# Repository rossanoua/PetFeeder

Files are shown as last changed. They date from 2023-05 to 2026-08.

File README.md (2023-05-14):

# PetFeeder

This is Arduino library for pet feeder.

### Hardware
- Arduino Uno.
- Stepper motor NEMA17 17HS4401, it will be used to push food through plastic tube with auger.
- Vibration motor, so that the feed does not get stuck in the pipe.
- 7 segment 4 digit LED display with TM1637 driver for display some info right on the feeder.
- A button, by clicking on it, feeder will push one portion of food for my pet.
- Tension sensor and HX711 to get to know what weight we need to push more.
- HC-06 bluetooth module, to have possibility to have some comfortable way to customise my feeder. 

### What inspired me
- Actually, the Arduino itself, to be honest.
- Another projects. Like [Gyver Feeder](https://github.com/AlexGyver/GyverFeed2)

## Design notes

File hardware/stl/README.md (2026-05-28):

# Printable meshes (STL)

Generated from `../cad/openscad/feeder_test_module.scad` — **the .scad is
the source of truth**, these are build artifacts. 3MF copies are in
`../3mf/` (OrcaSlicer reads both; 3MF preserves units, prefer it).

> OpenSCAD cannot export STEP (it is mesh-based, STEP is CAD/BREP).
> OrcaSlicer *does* import STEP, but for these parts STL/3MF is enough.

Regenerate after editing the model:

```sh
cd hardware/cad/openscad
for p in auger axle barrel hopper; do
  openscad -o ../../stl/$p.stl  -D "part=\"$p\"" feeder_test_module.scad
  openscad -o ../../3mf/$p.3mf -D "part=\"$p\"" feeder_test_module.scad
done
```

## Suggested print orientation (Stage 1 test, tune later)

- **auger** — vertical, shaft axis along Z, supports off / tree. The
  helical flight self-supports reasonably; a brim helps adhesion on the
  small base. This is the part most sensitive to print quality.
- **axle** — better to use a Ø5 mm steel rod. If printed: vertical,
  thin — expect flex and wear, test-only.
- **barrel** — vertical (bore along Z). Bore prints without supports;
  the inlet/socket may need light supports on its overhangs.
- **hopper** — print upside down (wide opening on the bed) so the cone
  and spout self-support; no supports inside the funnel.

All exported manifold (OpenSCAD `Simple: yes`). Fit clearances
(`fit_clear`, `join_clear`, `barrel_clear`) are guesses — adjust in the
.scad and reprint test coupons until the slip fits feel right on your
printer. Record results in `docs/mechanical-tests.md`.

## Paddle wheel parts (`pw_*`)

Source: `../cad/openscad/paddle_wheel_module.scad`. Same axle interface
(Ø5 mm with D-flat) as the auger, so one printed axle works for both
benchmarks.

```sh
cd hardware/cad/openscad
for p in wheel axle housing end_cap hopper; do
  openscad -o ../../stl/pw_$p.stl -D "part=\"$p\"" paddle_wheel_module.scad
  openscad -o ../../3mf/pw_$p.3mf -D "part=\"$p\"" paddle_wheel_module.scad
done
```

Suggested orientation:

- **pw_wheel** — flat on bed, hub axis vertical. Paddles on the bottom
  half (closer to the bed) self-support; no supports needed.
- **pw_axle** — use a Ø5 mm steel rod if possible.
- **pw_housing** — bed-down on the closed floor (open top facing up).
  No overhangs to support — the floor is flat and the outlet is a clean
  through-hole in the floor.
- **pw_end_cap** — flat on the bed, register lip pointing UP, boss
  pointing up. Boss has a flat overhanging roof — needs light supports
  if you print it cap-down. Or print boss-down (boss touching the bed)
  to avoid supports inside the socket. Pick whichever your slicer
  handles better.
- **pw_hopper** — upside down (wide opening on the bed).

Assembly order:
1. Slide the axle up through the housing's bottom bore (motor stub
   exits below the floor).
2. Drop the wheel onto the axle inside the housing (D-flat keys it).
3. Drop the cap onto the rim — the register lip seats in the recess,
   and the upper axle stub passes through the cap bore.
4. Slide the hopper spout into the boss-socket on top of the cap.

**Mounting note for Stage 1 tests:** the housing rests on its flat
floor BUT the outlet is in that floor. Prop the housing up on small
blocks under the rim (or place it over the bowl on a piece of cardboard
with a hole cut) so kibble can fall through the outlet into the bowl.
The motor coupler attached to the bottom axle stub also works as a
built-in standoff if the motor is mounted below the housing.

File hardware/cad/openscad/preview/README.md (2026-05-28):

# Preview renders

Visual reference only — **not authoritative**. The model is
`../feeder_test_module.scad`; regenerate after any change:

```sh
cd hardware/cad/openscad
xvfb-run -a openscad -o preview/auger.png    --imgsize=1000,700 --autocenter --viewall -D 'part="auger"'    feeder_test_module.scad
xvfb-run -a openscad -o preview/axle.png     --imgsize=1000,500 --autocenter --viewall -D 'part="axle"'     feeder_test_module.scad
xvfb-run -a openscad -o preview/barrel.png   --imgsize=1000,700 --camera=-260,30,46,0,0,46 -D 'part="barrel"'   feeder_test_module.scad
xvfb-run -a openscad -o preview/hopper.png   --imgsize=1000,700 --autocenter --viewall -D 'part="hopper"'   feeder_test_module.scad
xvfb-run -a openscad -o preview/assembly.png --imgsize=1000,750 --camera=-200,-200,150,0,0,35 -D 'part="assembly"' feeder_test_module.scad
```

(`xvfb-run` only needed on headless machines.)

- `auger.png`    — the screw, with the through D-bore for the axle
- `axle.png`     — drive axle: round stubs + D-flat over the middle
- `barrel.png`   — tube, viewed from the inlet side; rectangular socket
  collar with a conical funnel down into the bore (green = bore opened)
- `hopper.png`   — feed cone: round top → rectangular plug-in spout
- `assembly.png` — axle through auger, inside barrel, hopper spout
  seated in the collar socket

Verified with OpenSCAD 2021.01: all parts render `Simple: yes` (manifold,
printable); axle passes through the auger; hopper spout seats in the
collar; funnel leads from the socket into the bore.

Torque path: motor → axle round stub → D-flat → auger → food.
Use a real 5 mm steel rod as the axle if possible (printed axles flex).

---

## Paddle wheel module (`pw_*` files)

Alternative — and now primary — Stage 1 mechanism. Source:
`../paddle_wheel_module.scad`. Regenerate:

```sh
for p in wheel axle housing end_cap hopper; do
  xvfb-run -a openscad -o preview/pw_$p.png --imgsize=1000,750 --autocenter --viewall -D "part=\"$p\"" paddle_wheel_module.scad
done
xvfb-run -a openscad -o preview/pw_assembly.png --imgsize=1100,800 --autocenter --viewall -D 'part="assembly"' paddle_wheel_module.scad
```

- `pw_wheel.png`    — full-height hub + half-height paddles + D-bore
- `pw_axle.png`     — drive axle (round stubs + middle D-flat)
- `pw_housing.png`  — cup-shaped, closed floor with the rectangular
  OUTLET hole, OPEN top, rim recess for the cap
- `pw_housing_top.png` — top-down view; the outlet rectangle in the
  floor is clearly visible at 180° (left side of the disc) and the
  central axle bore at the centre
- `pw_end_cap.png`  — removable lid with the central axle bore + the
  radial-offset inlet hole, and the rectangular boss-socket on top
- `pw_hopper.png`   — feed cone; rectangular spout plugs into the cap
  boss-socket
- `pw_assembly.png` — wheel inside the housing, cap closing the top,
  hopper sitting above the cap with its spout in the boss; axle
  through everything (stubs visible top and bottom)
- `pw_assembly_top.png` — top-down view; inlet (cap boss) at +X / 0°,
  outlet (in the floor below) at 180°; non-coaxial offset = 180°

Real-world mounting: rotate the whole assembly 90° so the axle is
horizontal — then the hopper sits on top (gravity-fed), the chute drops
kibble down to the bowl below.

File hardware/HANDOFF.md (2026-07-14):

# AiPetFeeder — handoff (form 1a)

Стан на 2026-07-13, гілка `feature/feeder-compact-vibro`, останній коміт `72083c6`
(самофіксні стики: байонет + snap-детенти).
Документ для передачі іншому агенту: що це, з чого складається, які **числа не можна
чіпати не порахувавши**, і на які граблі я вже наступив.

---

## 1. Що це

Автогодівниця для кота. Форма **1a**: одна суцільна вежа **Ø160**, що стоїть **плазом
на власному дні** (ніг немає). Корм падає в **неглибокий лоток**, який висувається
вперед і стоїть на тензодатчику. Електроніка живе в кільцевому відсіку між мотором і
стінкою.

Друк: **AONE2 / Klipper**, поле **180 × 180 × 180** — усі деталі туди вписані.

| Вежа в зборі | Вибухова схема |
|---|---|
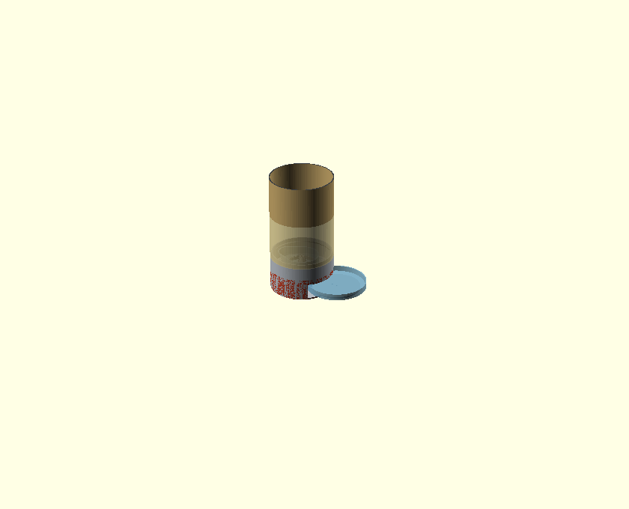
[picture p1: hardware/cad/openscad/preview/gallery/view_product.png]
Вежа в зборі
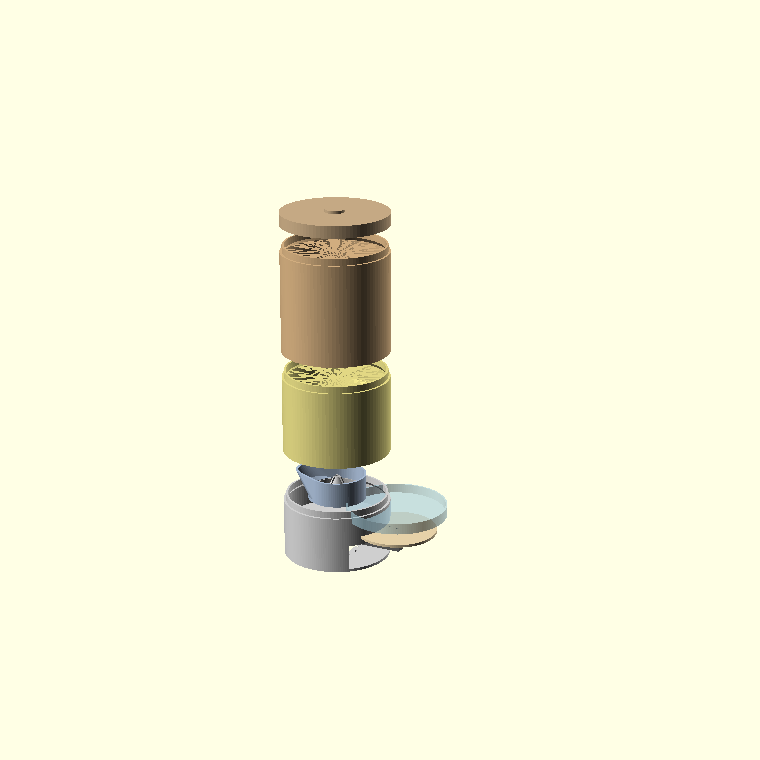
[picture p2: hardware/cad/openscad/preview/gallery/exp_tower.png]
Вибухова схема вежі
|  |  |

| Вибух: база | Вибух: лійка |
|---|---|
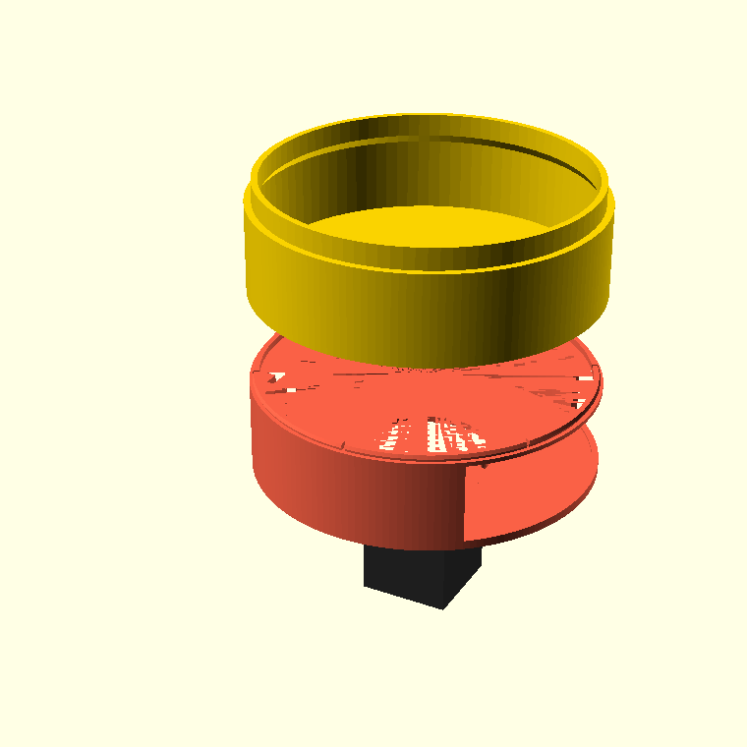
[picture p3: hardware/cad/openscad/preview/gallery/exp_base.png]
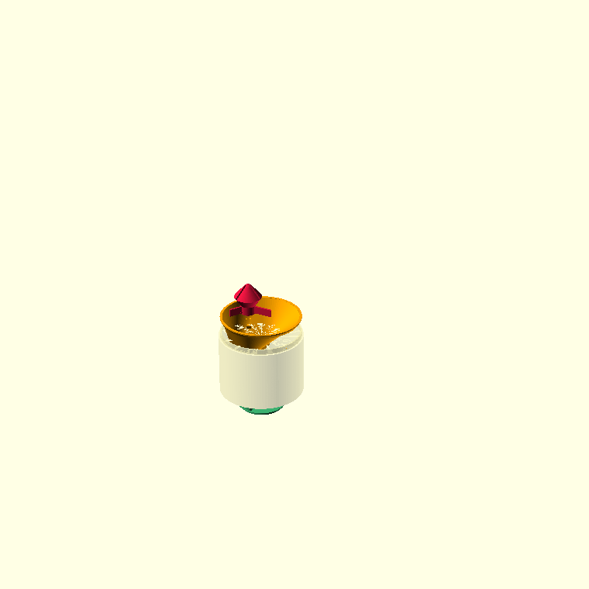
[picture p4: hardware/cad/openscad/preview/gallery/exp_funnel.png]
|  |  |

### Файли

| Файл | Що |
|---|---|
| `cad/openscad/bulk_hopper_module.scad` | **Головний.** Корпус, лійка, банка, лоток, вага, електроніка |
| `cad/openscad/paddle_wheel_module.scad` | Механізм: `wheel`, `housing`, `axle` |
| `cad/openscad/gallery_views.scad` | Розрізи/галерея (не друкується) |
| `cad/openscad/archive/chassis_module.scad` | **DEPRECATED**, не використовувати |
| `cad/openscad/preview/gallery/` | рендери кожної деталі + розрізи |
| `cad/openscad/preview/assembly/` | **як збирається**: step 0–9, розібрані види, розрізи тракту, turntable |

### Осі та z-площини

```
+X = ПЕРЕД (лоток, виток корму)      -X = ЗАД (сервісна панель, електроніка)
+Z = вгору,  z0 = земля (низ дна)

z0 ─── низ / земля
z3 ──── верх дна (sole_t=3); тут лежить load cell
z4 ──── низ ніші (niche_z0)
z40 ─── верх ніші (niche_h) — стеля скалопа
z43 ─── база деки / низ ДИСКА (base_deck_z) = грань мотора; ВИТОК виходить сюди
z48 ─── верх диска (base_motor_h) = підлога housing
z85 ─── верх бази (base_h) = верх housing; сюди сідає лійка
```

---

## 2. Деталі

### Друковані — 16

| # | part= | Габарит | Друк | Роль |
|---|---|---|---|---|
| 1 | `base_motor` | Ø160 × 46 | стоячи, z0 на стіл | Обичайка: дно, скалоп, пʼєдестал cell, рейки електроніки, сервісне вікно, snap-спігот |
| 2 | `base_hopper` | Ø160 × 52 | диском на стіл | Диск (z43–48) з витоком + комірцем; мотор під ним, housing над ним |
| 3 | `housing` (pw) | Ø88 × 37 | native 0° | Камера дозатора |
| 4 | `wheel` (pw) | Ø80 × 29 | плазом | Колесо, 3 лопаті, **Ø5 D-отвір → прямо на вал** |
| 5 | `axle` (pw) | Ø5 × 70 | стоячи | Опційна верхня вісь |
| 6 | `cap` | 110 × 88 × 14 | плазом | Кришка housing (`cap_plate`) |
| 7 | `shell` | Ø160 × 125 | стоячи | Оболонка лійки |
| 8 | `cone` | Ø153 × 83 | горлом донизу | Mass-flow конус |
| 9 | `spider_body` | Ø52 × 58 | куполом угору | Анти-джам, тіло |
| 10 | `spider_legs` | 3 × (95×60×14) | плазом | Анти-джам, 3 леза |
| 11 | `ring` | Ø160 × 160 | стоячи | Банка, ~2.79 л, стековна |
| 12 | `lid` | Ø160 × 22 | плазом | Верхня кришка |
| 13 | `tray` | Ø150 × 16 | плазом | Лоток-миска, ~280 мл |
| 14 | `cell_platform` | Ø120 × 6 | плазом | Площадка на cell |
| 15 | `el_tray` | 80 × 38 × 9 | плазом, стійками ВГОРУ | Плата-носій електроніки |
| 16 | `el_panel` | 50 × 42 × 4 | стоячи (дай brim) | Сервісна панель, DC-jack + USB |

Габарити зняті з **експортованих STL**, не з памʼяті.

### Галерея деталей

Усі рендери — `cad/openscad/preview/gallery/`, кожна деталь має `*_iso.png` і `*_side.png`.

| `base_motor` — обичайка | `base_hopper` — диск | `housing` — камера |
|---|---|---|
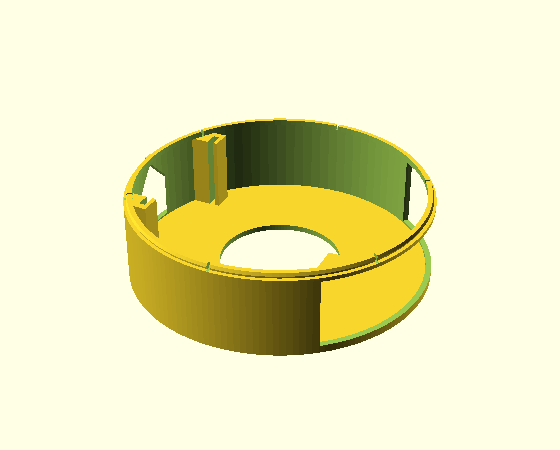
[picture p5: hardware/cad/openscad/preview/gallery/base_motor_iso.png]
base_motor
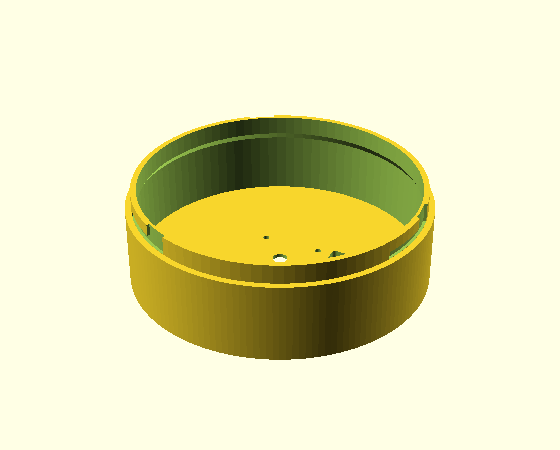
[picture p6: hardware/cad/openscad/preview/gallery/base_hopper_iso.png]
base_hopper
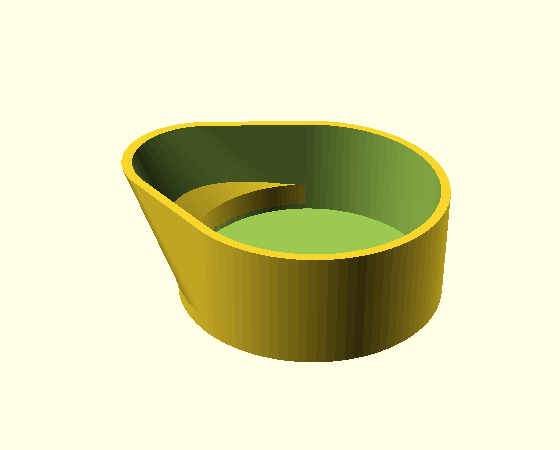
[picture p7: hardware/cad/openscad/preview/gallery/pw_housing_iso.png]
housing
|  |  |  |

| `wheel` — колесо | `cap` — кришка housing | `shell` — оболонка лійки |
|---|---|---|
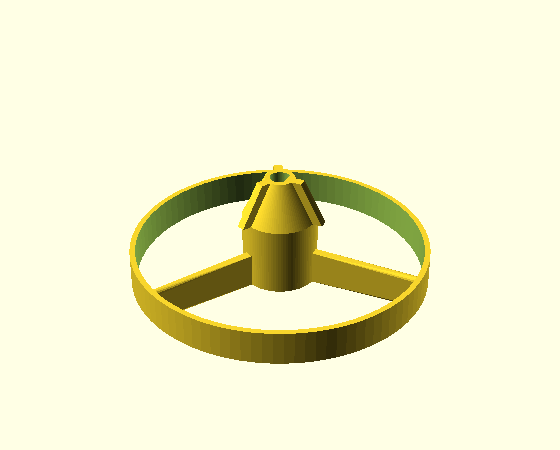
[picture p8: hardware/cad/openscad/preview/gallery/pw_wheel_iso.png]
wheel
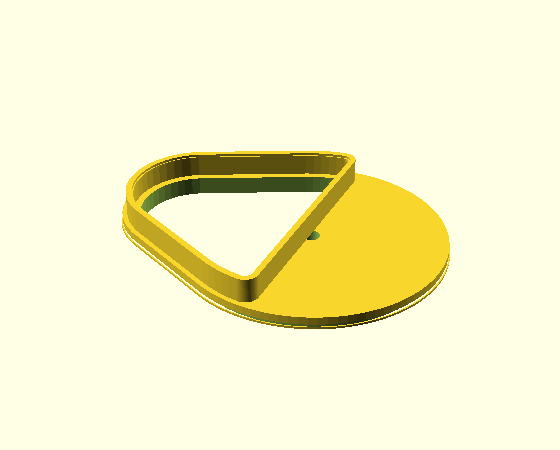
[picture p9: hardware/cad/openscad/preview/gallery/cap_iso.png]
cap
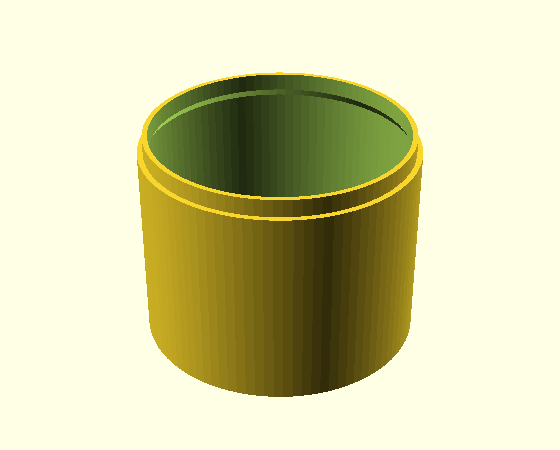
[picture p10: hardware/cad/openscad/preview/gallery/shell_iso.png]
shell
|  |  |  |

| `cone` — конус | `spider_body` — анти-джам | `spider_legs` — леза |
|---|---|---|
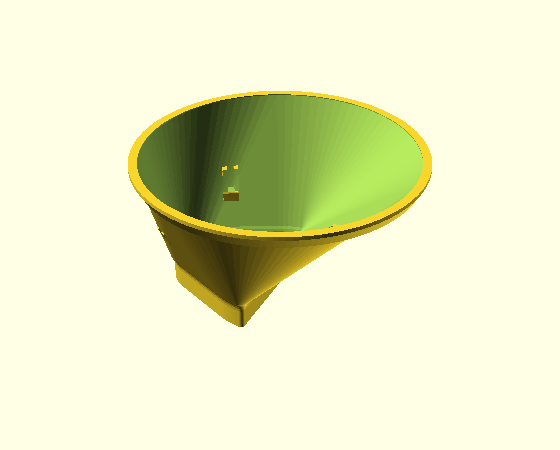
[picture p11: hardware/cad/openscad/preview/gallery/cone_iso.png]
cone
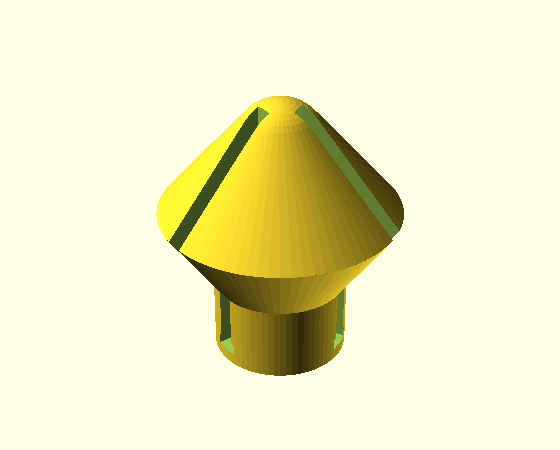
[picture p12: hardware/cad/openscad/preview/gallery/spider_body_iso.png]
spider_body
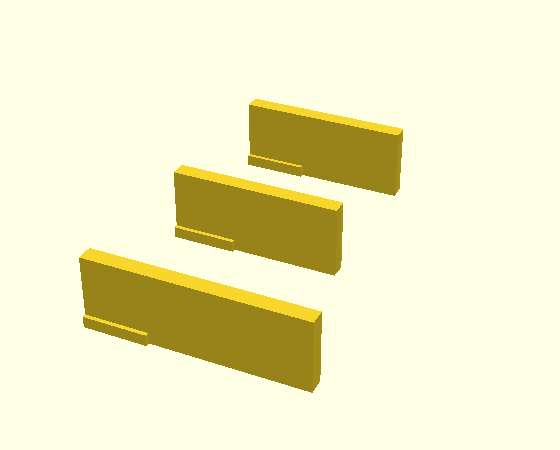
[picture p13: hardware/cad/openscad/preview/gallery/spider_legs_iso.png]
spider_legs
|  |  |  |

| `ring` — банка | `lid` — кришка | `tray` — лоток-миска |
|---|---|---|
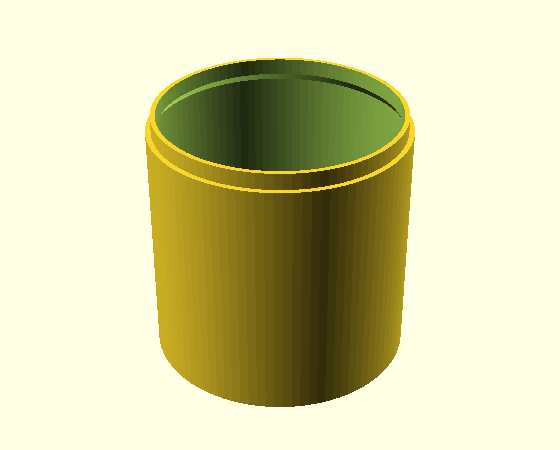
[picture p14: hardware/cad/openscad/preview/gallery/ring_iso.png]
ring
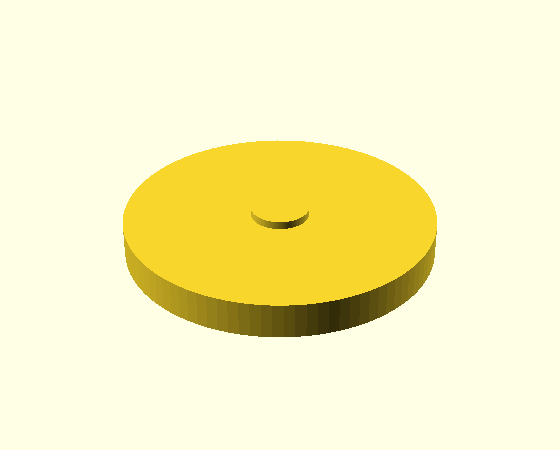
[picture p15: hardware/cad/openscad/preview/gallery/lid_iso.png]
lid
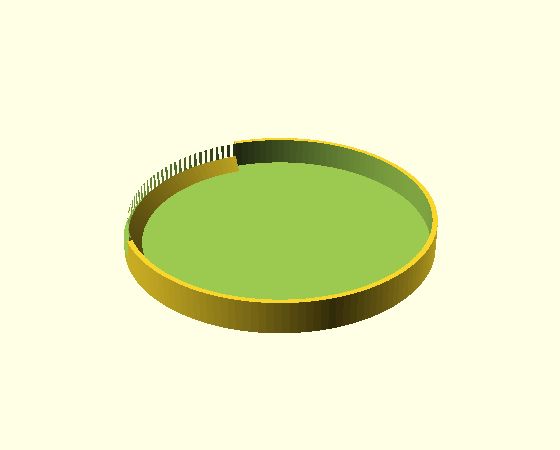
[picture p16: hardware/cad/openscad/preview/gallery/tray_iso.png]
tray
|  |  |  |

| `cell_platform` — площадка ваги | `el_tray` — плата-носій | `el_panel` — сервісна панель |
|---|---|---|
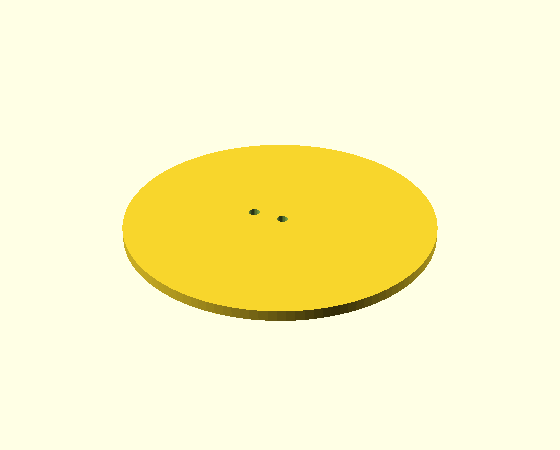
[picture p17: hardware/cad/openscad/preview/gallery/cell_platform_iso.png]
cell_platform
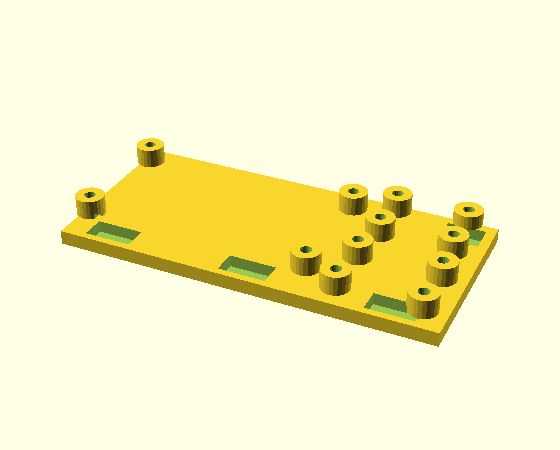
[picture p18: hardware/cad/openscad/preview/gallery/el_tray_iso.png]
el_tray
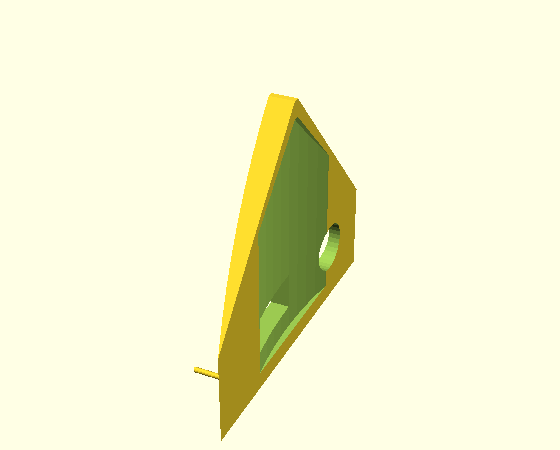
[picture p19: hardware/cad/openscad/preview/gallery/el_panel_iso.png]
el_panel
|  |  |  |

### Куплене

NEMA17 17HS4401 (Ø42.3, вал Ø5 D, довж. 40) · load cell 1–5 кг (80×12.7×12.7) ·
HX711 · ESP32 devkit (~52×28) · A4988/DRV8825 · DC-jack Ø8 · USB 12×6 ·
4×M3 (мотор), 4×M4 (cell), M2.5 саморізи (плати).

---

## 3. Як стикується

```
                    lid
                     │  стиковий замок
                    ring  ×N
                     │
      spider ──►  shell + cone
                     │   cone: пробка горла → комірець cap_plate (+ детент J4)
                  cap_plate
                     │   паз знизу ← верхня стінка housing (3.5 мм, + детент J4)
                  housing
                     │   виток підлоги ← КОМІРЕЦЬ диска (ключ + біди J3 = клацає)
   wheel ──────► base_hopper (ДИСК)   [колесо тримає cap зверху, зазор 1 мм — J1]
   (на вал)          │   snap-спігот + −X ключ
                 base_motor (ОБИЧАЙКА)
                     ▲   БАЙОНЕТ J2: 3 таби shell → 3 L-пази в замку бази (¼ оберту)
                     │
     NEMA17 ─── знизу крізь бор дна, 4×M3 у диск
     el_tray ── згори в 2 вертикальні рейки
     el_panel ─ зсередини у вікно (фланець + нібси J5 = не ходить)
     cell ───── на пʼєдестал (2×M4) → cell_platform (локатор J6) → tray зверху
```

Усі стики **самофіксні, без клею** — див. розділ 3a.

### Порядок збирання (жорсткий)

1. **NEMA17 у диск** (`base_hopper`) знизу: пілот у заглиблення, 4×M3.
2. **Колесо на вал** — Ø5 D-отвір, муфти немає.
3. **Housing на диск** — комірець диска входить у виток підлоги = ключ; **клацає** через біди J3.
4. **Електроніка в обичайку** — `el_tray` згори в рейки, потім `el_panel` у вікно (**клац** нібсами J5).
5. **Обичайка на диск** — snap клацає, −X ключ ловить орієнтацію.
6. **Вага** — cell на пʼєдестал → `cell_platform` → `tray` у локатор J6.
7. **Кришка + конус** — `cap_plate` **клацає** на housing (J4), `cone` пробкою в комірець (**клац** J4).
8. **Лійка** — `shell` над конусом, опустити й **провернути ¼ оберту** → байонет J2 клацає в замок.
9. **Банка + кришка** — `ring` ×N, `lid`.

> **Крок 1 має бути ПЕРШИМ.** Щойно обичайка клацне на диск — до гвинтів мотора вже
> не дістатись.
> **Крок 8 — байонет:** опустити оболонку так, щоб таби ввійшли в вертикальні канали,
> тоді провернути за годинниковою до клацання детента. Зняти — тільки зворотним ¼ оберту.

### Покроково (рендери — `part="step"`, `step=0..9`)

*Рендери в `preview/assembly/` згенеровано з коду цієї гілки; перегенерувати —
див. `preview/assembly/README.md`.*

| | | |
|---|---|---|
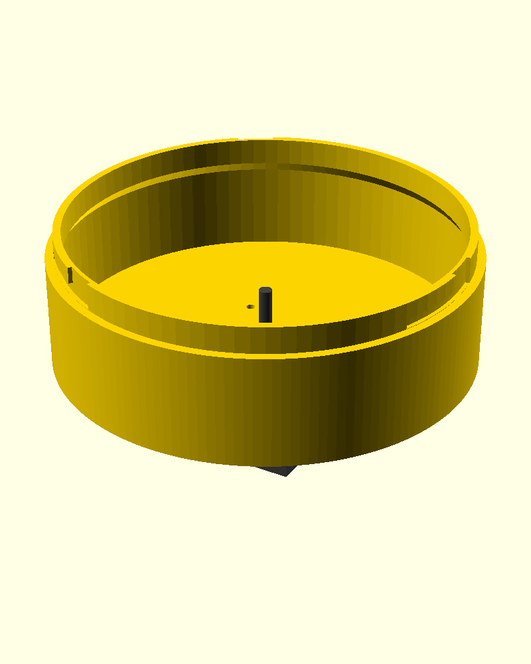
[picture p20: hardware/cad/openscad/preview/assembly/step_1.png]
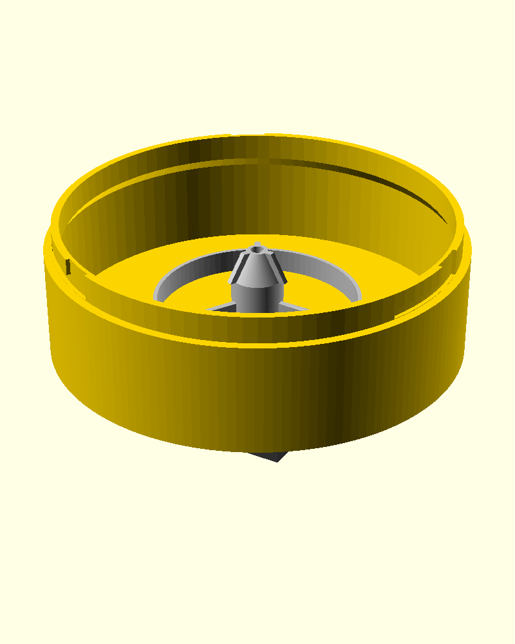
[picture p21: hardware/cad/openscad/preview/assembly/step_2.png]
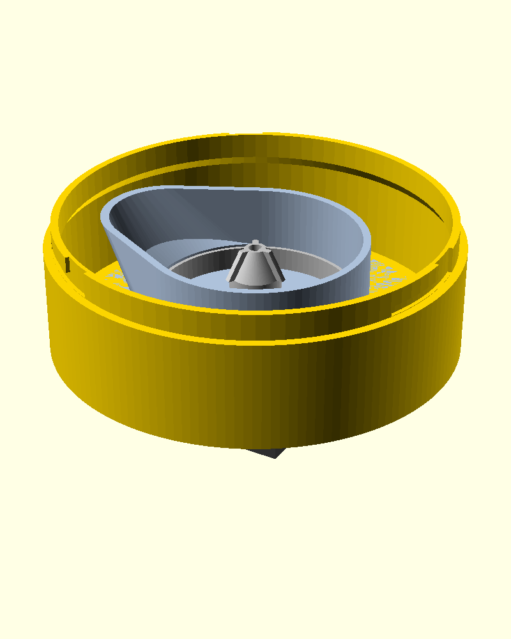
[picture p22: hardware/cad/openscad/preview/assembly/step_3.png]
| **1. Мотор + диск**<br> | **2. Колесо на вал**<br> | **3. Housing**<br> |
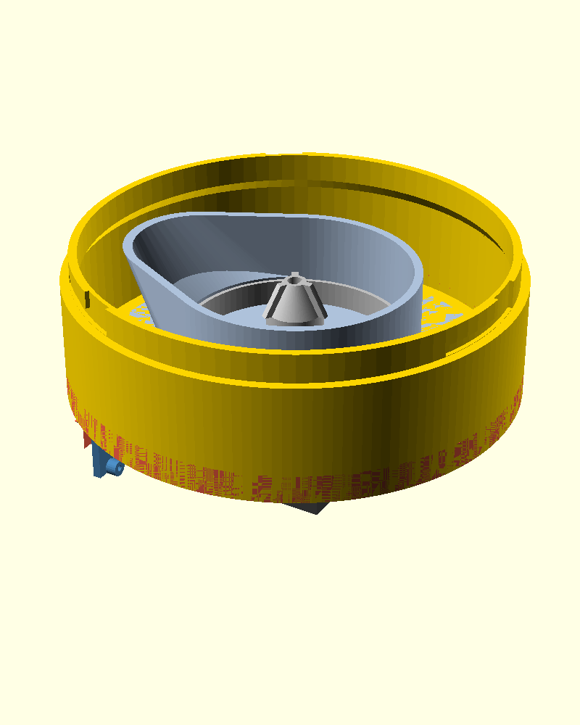
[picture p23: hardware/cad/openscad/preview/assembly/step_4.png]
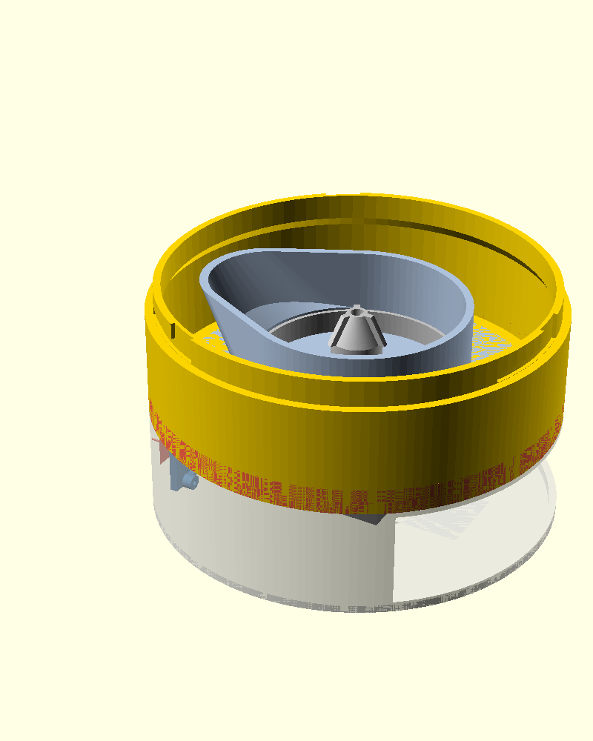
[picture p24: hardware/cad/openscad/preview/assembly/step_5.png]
| **4. Електроніка**<br> | **5. Обичайка (snap)**<br> | **6. Вага + лоток**<br> |
| **7. Кришка + конус**<br> | **8. Лійка (байонет)**<br> | **9. Банка + кришка**<br> |

Розібрані види (як роз'єднується): база / вежа / лійка

| Вежа розібрана | База | Лійка |
|---|---|---|

---

## 3a. 🔒 Самофіксні стики (без клею, без металу зверху)

Нижня половина була позиційована жорстко; верхній стек був слизьким гравітаційним
стосом. Ці вузли додають фіксацію — усі support-free, усі print-only.

Байонет вежа↔база
*J2 — оболонку піднято: у сірому замку бази видно L-паз (вертикальний вхід + горизонтальний хід).*

| # | Стик | Що додано | Тримає |
|---|---|---|---|
| **J1** | колесо ↔ вал | **нічого не треба** — верх колеса (мішалка z80.5) вже під cap (z81.5), зазор 1 мм | не злазить з вала (зачеп 15.5 мм) |
| **J2** | оболонка ↔ база | **байонет ¼ оберту**: 3 таби + 3 L-пази + ride-over детент | вежа не знімається без повороту |
| **J3** | housing ↔ диск | 2 біди 0.35 на стінках `ar`-комірця | housing лишається при знятій лійці |
| **J4** | cap↔housing, cone↔комірець | детенти 0.4 в пазу і в горловому комірці | підзбірка тримається в руці |
| **J5** | сервісна панель | 2 нібси 0.4 в кромках + ямки у вікні | не провалюється ні всередину, ні назовні |
| **J6** | лоток ↔ площадка | локатор-кільце 1 мм | лоток по центру, вага чесна |

**J1 — не «полагоджено», а перевірено, що не треба.** Бриф казав зазор 4.5 мм і counterbore.
Насправді верх колеса — не маточина (18), а центральна мішалка (z29→глоб. 80.5), і cap
низ 81.5. Колесо **вже** захоплено з зазором 1 мм, контакт — бос біля осі (низьке тертя).
**Не додавай counterbore.**

Перевірено на ізольованій геометрії: таб байонета чисто проходить вхідний канал (0 tris
перетину), а після повороту над ним є матеріал lip (24 tris) → не підніметься.

## 4. ⚠️ Числа, які не можна чіпати наосліп

Розрізи до кожного пункту (повний набір — `cad/openscad/preview/gallery/sec_*.png`,
відтворюються з `gallery_views.scad`):

| Шлях корму (розріз по Y) | База в розрізі: дно, cell, лоток |
|---|---|
| Шлях корму | База в розрізі |
| Банка → конус → housing → колесо → виток → комірець → диск → **лоток** | Дно z0–3, cell на пʼєдесталі, площадка, лоток висувається вперед |

| Відсік електроніки — згори (зріз z14–22) | Відсік — збоку |
|---|---|
| Відсік згори | Відсік збоку |
| Синє — `el_tray` **ребром** у рейках ззаду; квадрат у центрі — мотор | Плата на всю висоту відсіку (z3–41); червоне — сервісна панель |

### 4.1 Виток корму — затиснутий з ЧОТИРЬОХ боків

`hole_radial_in = 23`, `hole_radial_out = 36`, `hole_w = 34`
(**MUST MATCH в обох файлах** — `bulk_hopper` і `paddle_wheel`).

Найвужче місце тракту — **бор anti-rotation комірця** `ar_bx × ar_by = 10.1 × 31.1`.
Комірець вставляється У виток housing, тому його бор **фізично не може** бути ширшим за
сам виток. Єдиний спосіб розширити — збільшити `hole_len = out − in`.

| Межа | Значення | Запас зараз |
|---|---|---|
| `in` > мотор r21 | 23 | 2.0 |
| `in` > заднього обода лотка | 23 vs x23 | 0 (див. нижче) |
| `out` < обода колеса (38.5) | 36 | 2.5 |
| **кут** отвору < `hr_in` 40.8 | 39.2 | **1.6** |

**Кут — це не край.** Отвір прямокутний: `hypot(out−2, hole_w/2−2)+2`.
При `out = 38` кут лягає на **41.0** і **пробиває стінку housing**. Стеля — **37**.

**Задня стінка лотка — рампа, а не запас.** Виток іде з x23, але внутрішня підлога
лотка не може початись раніше x25.5 (зовн. зад x23 + стінка 2.5). Посунути лоток назад
не можна (зад впритул до мотора r21), виток уперед — заб'є бор. Тому **задня стінка лотка
занижена й має 45° рампу всередину** (`tray_ramp_a/tray_ramp_h`) — корм із неї зсипається
в лоток, а не сидить на полиці. НЕ повертай стирту цифру «запас 2.5».

### 4.2 Ніша НЕ СМІЄ доходити до диска

`niche_h = 40`, а диск на z43–48.

Раніше `niche_h` було 58 і `base_niche()` викликалась **і в `base_hopper`** → скалоп
**різав диск наскрізь**: знищував виток, знищував стопорний комірець, і housing стояв
передньою половиною в повітрі. Перерізом підтверджено: диск був суцільний тільки до x≈19.

Зараз `base_hopper` **не викликає** `base_niche()`. Диск = дах ніші.

### 4.3 Відсік електроніки — лише 43 мм заввишки

Мотор висить на всю висоту бази. Тому:
- **плата стоїть РЕБРОМ** (`el_tray` 80×38), а не лежить на поличці;
- горизонтальна полиця в трубі, що друкується стоячи = стеля = **підтримки**;
- усе додане в базу — **вертикальне**: рейки вздовж Z, пази вздовж Z, вікно з **45° gable-дахом**.

Рейки на ±40 мм від осі сектора (`el_sector = 180`, навпроти виходу).
Стійки плати дивляться **до мотора** — там 26 мм, до стінки лише 19.

### 4.4 Лоток — 16 мм, не більше

Бюджет знизу: земля + cell (12.7) + зазор 2 + площадка (4) → підлога лотка **z21.7**.
Лоток мусить **ще й висунутись** під дахом скалопа (z40).

| `tray_h` | обід | висув під дах | падіння корму |
|---|---|---|---|
| 16 | 37.7 | **2.3** ✓ | 5.3 |
| 20 | 41.7 | **−1.7** ✗ | 1.3 |

При 20 мм лоток **не дістати** взагалі.

### 4.5 Синхрон між файлами

`hole_radial_in`, `hole_radial_out`, `hole_w`, `hole_corner_r`, `collar_h`/`cap_collar_h`,
teardrop-набір, `housing_h`/`pw_housing_h2` — **дублюються вручну**. Після зміни звіряй:

```sh
openscad -o /dev/null -D 'part="wheel"' paddle_wheel_module.scad 2>&1 | grep ECHO
# має бути hole=13x34 at r_mid=29.5
```

---

## 5. 🪤 Граблі (на яких я вже наступив)

### OpenSCAD

- **`--render` (CGAL) ІГНОРУЄ `color()`.** Кольорові збірки/розрізи рендеряться тільки
  в preview-режимі (без `--render`).
- **`intersection()` навколо різнокольорового `union()`** — OpenCSG сплющує все в один
  колір. У `gallery_views.scad` кожна деталь ріжеться **окремо** (див. `module piece()`).
- **`include <bulk_hopper_module.scad>` перезаписує `part = "assembly"`** і домальовує
  свою збірку поверх твого виду. Присвой `part = "none"` **ПІСЛЯ** include.
- **Прев'ю бреше про різьбу.** `linear_extrude(twist)` як **додане** тіло рендериться в
  прев'ю, але **зникає на F6/CGAL-експорті**. Завжди перевіряй експортований STL
  перерізом у зоні різьби.
- **`include<>` резолвиться відносно ФАЙЛУ-ІНКЛЮДЕРА, не cwd.** Тому чек-скрипт у `/tmp`
  отримує **undef усі змінні** з модуля, і кожен `intersection()` виходить порожнім —
  що читається як «чисто», хоча нічого не рахувалось. Тримай чеки поруч із модулем
  (`_chk.scad`). Це знецінило один мій попередній набір «7 перевірок чисто».
- **Змінна = f(іншої змінної) → порядок має значення.** `bay_tab_ang = bay_tab_w/...`,
  визначена **вище** за `bay_tab_w`, дала `undef`, і `rotate_extrude(angle=undef)`
  намалював **повне кільце** замість дуги (таб байонета став суцільним обручем). Похідні —
  завжди ПІСЛЯ параметрів, від яких залежать.
- **`hull()` двох `rotate_extrude`-дуг лишає сміття тесселяції**, що читається як колізія.
  Роби таб одним `rotate_extrude` трапеції-полігону.

### Слайсер (OrcaSlicer)

- **Глухий різьбовий карман, друкований отвором ВНИЗ, забивається infill** — отвір
  друкується суцільним. Лікується наскрізним бором. (Це вже не актуально — ноги
  видалені — але клас бага той самий для будь-якого глухого кармана.)
- **`center_stl` кладе центр по bbox.** Ніша робить bbox несиметричним, тому центр
  труби в gcode — **(111.4, 95)**, а не (95,95). Рахуй центри отворів через зсув bbox,
  інакше всі заміри падають не туди (я через це двічі «підтвердив» неправильний фікс).

### Метод перевірки, який працює

- Переріз STL → ray-cast → друкувати **прольоти** (spans), а не булеве «solid/void»:
  парність легко ламається на вершинах.
- Перевірка на перетин: `intersection()` двох деталей → експорт STL → **0 трикутників =
  чисто**.
- Слайс і заміри по **gcode**, не по STL: STL може мати отвір, який слайсер закриє.

---

## 6. Що НЕ зроблено

- **Вібромотор** — кріплення відсутнє (причина назви гілки `-vibro`). Опційно: spider
  тримає потік.
- **Отвори під стійки на `el_tray`** — я взяв типові патерни ESP32/A4988/HX711.
  **Звір із реальними платами** перед друком (`esp_holes`, `drv_holes`, `hx_holes`).
- **`shared_params.scad`** — спільні `hole_*`/`collar_h`/teardrop досі дублюються
  вручну в двох файлах. Варто винести.
- **Пʼєдестал cell** підходить до NEMA17 на **1 мм** (x22 vs корпус x21). Перетину
  немає, але допуск тонкий.
- **Самофікси не калібровані на реальному пластику.** Байонет-детент 0.35, біди J3 0.35,
  детенти J4/J5 0.4 — це стартові значення; перший друк покаже, чи клацає з потрібним
  зусиллям. Геометрично перевірено (таб проходить / замок тримає), тактильно — ні.
- Нічого з цього **не друкувалось у металі** — форма 1a ще не надрукована жодного разу.

---

## 7. Друк / деплой

Скіл `aone2-slice-deploy`: NUC → macmini (OrcaSlicer + профіль `~/Downloads/petFeeder.3mf`)
→ Pi `raspb5` (`~/AONE21_data/gcodes/petFeeder/`).

```sh
# на Mac
python3 pf_make.py <stl> <name>          # слайс + post-process
python3 pf_thumb.py g_<name>/plate_1.gcode <48.png> <300.png>   # thumbnail
```

**STL має бути binary** (`--export-format binstl`) — ASCII не центрується в `pf_make`.

Принцип користувача: **підтримки = сміття = гроші.** Дизайн має бути support-free.

---

## 8. Як перегенерувати картинки

Усі рендери в цьому файлі лежать у `cad/openscad/preview/gallery/`.

```sh
cd hardware/cad/openscad

# одна деталь, 2 ракурси (БЕЗ --render: інакше злетять кольори)
xvfb-run -a openscad -o preview/gallery/tray_iso.png  --imgsize=560,450 \
  --viewall --autocenter --camera=0,0,0,58,0,25,0 -D 'part="tray"' bulk_hopper_module.scad
xvfb-run -a openscad -o preview/gallery/tray_side.png --imgsize=560,450 \
  --viewall --autocenter --camera=0,0,0,90,0,0,0  -D 'part="tray"' bulk_hopper_module.scad

# розрізи (gallery_views.scad): view = product | base | food ; cut = none | slab | xhalf | yhalf
xvfb-run -a openscad -o preview/gallery/sec_food.png --imgsize=840,680 --viewall --autocenter \
  --camera=0,0,0,76,0,195,0 -D 'view="food"' -D 'cut="yhalf"' gallery_views.scad
```

Камера — `--camera=tx,ty,tz,rx,ry,rz,dist`; з `--viewall` дистанція 0 = автопідбір.
`cut="yhalf"` лишає **y<0**, тому щоб бачити площину зрізу, дивись з **+Y** (rz ≈ 180–200).

Візуальний довідник цією ж галереєю (деталі + розрізи + порядок збирання):
<https://claude.ai/code/artifact/f1700034-7984-4b45-b9b1-5870580ef21e>

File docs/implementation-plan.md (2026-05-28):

# AiPetFeeder — Implementation Plan

Synthesizes `hardware/bom.md`, `docs/project-notes.md` and the OpenSCAD
models into a concrete functional plan: what each BOM component does,
how the firmware ties them together, and the order in which we add
capability. Every line item in the BOM has a defined role; nothing is
"bought because it's listed."

## TL;DR

A **closed-loop, weight-validated paddle-wheel dispenser**, controlled
by an ESP32 running ESPHome. Manual button + status display + scheduled
feeds + Home Assistant integration (no cloud). HX711 weighs every
portion; rotation continues until the target weight is reached, and
absence of weight change after rotation is the jam signal — so the
mechanism and the sensor share one feedback loop.

---

## 1. Component → function map

| BOM line | Role in the system | Phase |
|---|---|---|
| Paddle wheel + housing + end cap (5a, 5b, 5c) | Primary dosing mechanism. One pocket ≈ one portion increment. | Stage 1 |
| Hopper (8) | Gravity feed into the wheel pocket; rectangular spout plugs into the housing socket. | Stage 1 |
| Drive axle (7) + motor coupler (7b) | Transmit torque from NEMA17 to the wheel via the D-flat. Same axle works for both wheel and auger benchmark. | Stage 1 |
| Auger + barrel (6a, 6b) | **Benchmark only.** Quantify jam rate vs the paddle wheel on the same kibble, then archive. | Stage 1 |
| NEMA17 stepper (1) | Discrete, repeatable rotation. Step-counted "pockets per command" → coarse open-loop dose, weight loop refines. | Stage 1 |
| Stepper driver A4988 / DRV8825 (2) | Microstepping (1/8 or 1/16) for low-noise smooth rotation. EN pin gated by ESP32 → motor de-energised between feeds (cool + silent). | Stage 1 |
| ESP32 dev board (3) | All control + Wi-Fi + HA + OTA. One MCU does everything. | Stage 1 |
| 12 V / ≥2 A PSU (4) | Powers the stepper motor; on-board buck or USB powers the ESP32 logic. Common ground. | Stage 1 |
| Vibration motor (11, optional) | Only if hopper bridges. Driven by a logic-level FET, pulsed during a feed if delta-weight stalls before the timeout. | Stage 1 (conditional) |
| Load cell 1–5 kg + HX711 (Stage 2: 1, 2) | The feedback half of the loop. Closes "did the portion actually arrive?", drives jam detection, exposes bowl_weight as a HA sensor. | Stage 2 |
| Momentary button (Stage 2: 3) | INPUT_PULLUP. Short press = feed one default portion. Long press = tare. | Stage 2 |
| TM1637 4×7-seg display (Stage 2: 4) | Idle: clock. Feeding: grams remaining countdown. Error: short code (`E001` etc.). Upgrade path: SSD1306 OLED for richer status. | Stage 2 |
| Printed enclosure (Stage 2: 5) | Holds motor, board, bowl, hopper. Designed *after* mechanism is locked. | Stage 2 |
| M3 screws / heat-set inserts (10) | All assemblies that need rework (motor mount, electronics tray, future end-cap screws). | Both |

Explicitly **not used**: HC-06 (ESP32 has Wi-Fi); any cloud service
(local-first by design).

---

## 2. Functional architecture

### Food path (mechanical)

```
                ┌──────────────────┐
                │   Feed hopper    │   ← refill here
                │   (cone, open)   │
                └────────┬─────────┘
                         │  gravity
                         ▼
                ┌──────────────────┐
                │   Inlet boss     │   spout plugged into socket
                │   + inlet slot   │
                └────────┬─────────┘
                         │  pocket fills
                         ▼
        ╔════════════════╧═════════════════╗
        ║                                  ║
        ║    PADDLE WHEEL inside HOUSING   ║   ← removable end_cap on top
        ║    axle ── D-flat ── wheel       ║
        ║                                  ║
        ╚════════════════╤═════════════════╝
                         │  pocket inverts at the bottom
                         ▼
                ┌──────────────────┐
                │  Outlet chute    │   widens downward
                └────────┬─────────┘
                         │  gravity
                         ▼
                ┌──────────────────┐
                │  BOWL on plate   │   ◄── load cell
                └──────────────────┘
                         │
                         ▼ (sensed weight)
```

### Signal / control path (electrical)

```
                       ┌────────────────────────────────┐
                       │            ESP32               │
                       │     (ESPHome firmware)         │
        button ─GPIO──►│                                │
                       │  Wi-Fi + mDNS + HA native API  │◄─── Home Assistant
        HX711 ─dout───►│  OTA updates                   │     phone / web UI
              ─sck────│  cron-style schedule           │
                       │  Feed FSM (see §3)             │
        TM1637 ◄─DIO───│                                │
               ◄─CLK───│                                │
                       │                                │
                       │  STEP   DIR   EN               │
                       └────┬─────┬─────┬───────────────┘
                            ▼     ▼     ▼
                       ┌──────────────────┐    12 V ──► MOT  ─────┐
                       │  A4988 / DRV8825 │                       │
                       └────────┬─────────┘                       ▼
                                ▼                            NEMA17
                       (microstepping pulses)                   │
                                                     coupler ───┤
                                                                ▼
                                                              axle ─ D ─ wheel
                       (optional)
                       FET ──► vibration motor on the hopper wall
```

### Power

```
   12 V / 2 A PSU ──┬── stepper driver V_MOT (NEMA17 only)
                    └── buck or LDO → 5 V → ESP32 (Vin), HX711, display, button
   (all GNDs tied to one star point near the ESP32)
```

---

## 3. Control loops & state machine

### Feed state machine (per "feed N grams" command)

```
   IDLE
     │  command: feed(target_g)
     ▼
   ARMING ──► tare offset checked, EN low → motor on
     │
     ▼
   ROTATING ── step pocket_arc (= 360° / n_paddles) ──┐
     │                                                │
     ▼                                                │
   SETTLING ── wait HX711 settle (≈ 300 ms) ──────────┘
     │
     ├──► delta_g > 0  AND  total_g < target_g   → ROTATING (next pocket)
     ├──► total_g ≥ target_g                     → DONE
     ├──► delta_g ≈ 0  for K consecutive pockets → JAM_RECOVER
     └──► elapsed > timeout                      → ERROR
   JAM_RECOVER
     │  reverse by ~30°, optionally pulse vibration motor, then ROTATING
     │  give up after R retries → ERROR (publish to HA)
     ▼
   DONE / ERROR → EN high (motor off, cool), report dispensed_g
```

### Why this works

- **Open-loop count of pockets** gives a coarse first guess.
- **Weight delta after each pocket** is the truth source — bypasses
  pocket-fill variance and kibble density drift.
- **No weight change after rotation** is the only thing we need to call
  "jam OR empty hopper" — distinguishing them is a v1+ refinement
  (current sense, hopper switch).

### Manual button

| Action | Behaviour |
|---|---|
| Short press (< 500 ms) | `feed(default_portion_g)` |
| Long press (≥ 2 s) | `tare()` (zero the bowl) |
| Held during boot | (future) reset Wi-Fi credentials |

### Schedule

ESPHome `time` + `script.execute` at configured times. Times and
default portion live in HA UI (not hard-coded). Persisted across
reboots.

---

## 4. Feature priority

| # | Feature | M0 | M1 | M2 | M3+ |
|---|---|:--:|:--:|:--:|:---:|
| 1 | Spin stepper N pockets (open-loop, no sensors) | ✓ | | | |
| 2 | Manual button → feed default portion | ✓ | | | |
| 3 | Wi-Fi + ESPHome + Home Assistant discovery | ✓ | | | |
| 4 | OTA firmware updates | ✓ | | | |
| 5 | TM1637 status (idle / feeding / error) | ✓ | | | |
| 6 | HX711 closed-loop weight per feed | | ✓ | | |
| 7 | Jam detection via weight delta | | ✓ | | |
| 8 | Scheduled feeds (cron-like via HA) | | ✓ | | |
| 9 | Persistent counters (NVS): total dispensed, last feed | | ✓ | | |
| 10 | Reverse-on-jam recovery + retry budget | | | ✓ | |
| 11 | Vibration motor pulse on stall | | | ✓ | |
| 12 | Hopper-low detection (stall pattern → notify HA) | | | ✓ | |
| 13 | TMC2208 driver + StallGuard (cleaner jam signal) | | | | ✓ |
| 14 | Replace TM1637 with SSD1306 OLED (richer UI) | | | | ✓ |
| 15 | Cat detection / per-cat schedules | | | | ✓ |

`Mn` = milestone, not a deadline.

---

## 5. Roadmap aligned to BOM

| Phase | Hardware delivered | Firmware delivered | Gate to next |
|---|---|---|---|
| **S1-mech** *(now)* | Print + assemble paddle wheel kit. Auger printed as benchmark only. | None. | Food feeds without jamming for N consecutive portions on real kibble. Recorded in `mechanical-tests.md`. |
| **M0 — open-loop firmware** | NEMA17 + driver + ESP32 wired up; no scale yet. | ESPHome project: stepper, button, display, Wi-Fi, OTA, HA discovery. `feed(pockets)` action. | Pressing the button dispenses one repeatable portion via HA. |
| **M1 — closed-loop** | Add HX711 + load cell under a temporary bowl plate. | Add HX711 to ESPHome; switch `feed()` to grams target; jam-by-weight-delta. Schedule. | Feeding 5 / 10 / 15 g via HA hits target ± tolerance; jam is reported, not silent. |
| **M2 — robustness** | Optional vibration motor if S1-mech / M1 testing showed bridging. | Reverse-on-jam, retry budget, hopper-low notification. | Two weeks unattended with no manual intervention. |
| **S2-enclosure** | Designed printed enclosure (separate `.scad`), load-cell bowl mount, electronics tray. | No new firmware. | Aesthetically and serviceably acceptable for use. |
| **M3+** | Driver swap to TMC2208; OLED swap. | StallGuard-based jam; richer display. | Optional. |

---

## 6. Firmware stack — recommendation

**Default: ESPHome.** Reasons:

- Native components for everything we use: `stepper`, `hx711`, `button`,
  `tm1637`, `output` (FET), `wifi`, `ota`, `api`, `time`, `script`,
  `schedule`. Less hand-rolled code per feature.
- First-class Home Assistant integration: every sensor, button, and
  service appears automatically.
- YAML config is reviewable in PRs; secrets in `secrets.yaml`.

**Escape hatch:** if the closed-loop logic gets too tangled inside YAML
scripts, drop into a `custom_component` (C++) for the FSM only, keep the
rest declarative. Last resort: full PlatformIO / Arduino, lose HA
auto-discovery (would need Web Server + REST).

**Topology in repo (planned, not built):**

```
firmware/
  esphome/
    aipetfeeder.yaml         # main config
    secrets.yaml.example
    fsm/                     # optional custom_component (C++) for feed FSM
    README.md                # build + flash instructions
```

---

## 7. HA-side surface (what the user sees)

| HA entity | Type | What it does |
|---|---|---|
| `button.feeder_feed_now` | Button | Triggers default portion |
| `number.feeder_default_portion_g` | Number | Default portion size |
| `sensor.feeder_bowl_weight_g` | Sensor | Live weight from HX711 |
| `sensor.feeder_total_dispensed_g` | Sensor | Lifetime counter (NVS) |
| `sensor.feeder_last_feed_time` | Timestamp | When the last successful feed completed |
| `binary_sensor.feeder_jam` | Binary | True during a JAM_RECOVER/ERROR state |
| `button.feeder_tare` | Button | Re-zero the scale |
| `switch.feeder_motor_enable` | Switch | (Debug) hold EN low manually |

Automations live in HA, not in the feeder — e.g. "if `total_dispensed`
hasn't increased today by 18:00, send a phone notification."

---

## 8. Out of scope (deliberately)

- **HC-06 / Bluetooth** — superseded by ESP32 Wi-Fi.
- **Cloud account / vendor app** — local-first by design.
- **Per-cat identification** — out of scope unless we later add RFID.
- **Camera** — out of scope.
- **Battery operation** — wall-powered only; pet feeders need to be
  always-on.
- **Auger in production firmware** — auger is benchmark-only; once
  M0 begins, the firmware targets the paddle wheel.

---

## 9. Open decisions to resolve before M0

1. Microstepping resolution: 1/8 vs 1/16 (driver-dependent; smoother
   ≠ better if torque drops).
2. Stepper speed at which kibble actually transfers cleanly — measured
   during S1-mech testing.
3. Where the bowl sits relative to the chute — affects bowl plate
   design (impacts S2-enclosure, not M0).
4. Default portion size — depends on the actual cat; record in tests.
5. Driver IC choice for the *built* prototype: A4988 cheapest, DRV8825
   higher torque, TMC2208 quieter + StallGuard. **Default A4988 for
   M0**; revisit at M3.

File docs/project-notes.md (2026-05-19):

# PetFeeder / AiPetFeeder project notes

> Notes from discussion about restarting the PetFeeder idea and turning it into a more structured AiPetFeeder project.

## General idea

The project idea is an automatic pet feeder, mainly for cats. The intended new project name is **AiPetFeeder**.

The old GitHub repository is:

- `rossanoua/PetFeeder`

The current repo should be treated mostly as an early prototype / source of ideas. A new clean repository may make more sense for the next implementation.

## Existing repository findings

The old repository contains an Arduino library skeleton for a pet feeder.

The `README.md` describes the following hardware idea:

- Arduino Uno
- Stepper motor NEMA17 17HS4401
- Auger inside a plastic tube to push food
- Vibration motor to prevent food from getting stuck
- TM1637 4-digit 7-segment display
- Button to dispense one portion
- Load cell / tension sensor + HX711 to measure weight
- HC-06 Bluetooth module for configuration
- Inspiration from GyverFeed2

The `dev` branch contains GitHub Actions workflow for Arduino unit tests:

- `.github/workflows/petfeeder-tests.yml`
- Uses Ruby and `arduino_ci`
- Runs tests from `libraries/PetFeeder`

The library metadata contains:

- `name=PetFeeder`
- `architectures=avr,esp8266`
- `includes=PetFeeder.h`
- `depends=HX711,AccelStepper,TM1637`

## Initial technical conclusion

The old project is not a complete feeder implementation. It looks like:

- Arduino library skeleton
- early hardware concept
- first attempt to add CI tests

It may be faster and cleaner to start a new implementation rather than continue the old code directly.

## Recommended direction

For a new MVP, prefer:

- ESP32 instead of Arduino Uno
- Wi-Fi / local API / Home Assistant support
- Stepper motor for food dosing
- HX711 + load cell for portion control
- Anti-jam logic
- Optional display and button

Bluetooth HC-06 is probably not needed if ESP32 is used.

## Core MVP

Minimum useful prototype:

1. Dispense one portion by button.
2. Dispense one portion via API / Home Assistant.
3. Measure bowl or output weight using HX711 + load cell.
4. Stop dispensing when target weight is reached.
5. Detect possible jam by timeout / missing weight change / motor behavior.
6. Try anti-jam sequence: reverse stepper, vibrate, retry.

## Motor discussion

There was confusion between servo and stepper motor.

For this project, the important motor is the **stepper motor** driving the auger.

### NEMA17

NEMA17 is still the safest option for the first working prototype.

Reasons:

- Good torque reserve
- Common and easy to mount
- Works well with auger mechanics
- Easy to control dosing by steps
- Allows reverse motion for anti-jam

A full-size NEMA17 such as 17HS4401 may be slightly large, but it is a good first choice because food can jam or compact inside the tube.

### Smaller motor options

Possible alternatives:

- Shorter NEMA17, for example 34 mm or 40 mm body length
- NEMA14 if the auger is small and friction is low
- 28BYJ-48 only for very light tests, not recommended for final feeder mechanics

Recommended approach:

1. Start with NEMA17.
2. Test real food with the auger.
3. If torque is clearly excessive, move to shorter NEMA17 or NEMA14.

## Mechanical concept

Recommended first mechanical test module:

- Stepper mount
- Auger tube
- Auger
- Output nozzle
- Simple test hopper

Do not start with the full finished case. First validate the feeding mechanism.

Questions to validate with the first print:

- Does the food move reliably?
- Does it jam?
- Is the portion reasonably repeatable?
- Is vibration needed?
- What auger diameter and pitch work best?
- Is the selected stepper strong enough?

## 3D modeling discussion

Blender is not the best main tool for this project. It is better for visual/organic modeling and renders.

For mechanical parts, use CAD / parametric modeling.

Recommended tools:

### OpenSCAD

Good for simple parametric mechanical parts and GitHub workflow.

Pros:

- Text-based
- Easy to version in Git
- Good for reproducible STL generation
- Good fit for brackets, mounts, tubes, simple enclosures

### FreeCAD

Good free CAD option for more complex mechanical parts.

Pros:

- Parametric CAD
- Better for exact dimensions, sketches, constraints
- Can export STL / STEP
- Good for cases, covers, brackets, load cell mounts

### Blender

Useful later for:

- Visual design
- Renders
- Marketing images
- Cosmetic body shapes

But not recommended as the primary CAD tool for motor mounts, load cell brackets, screw holes, and auger mechanism.

## Suggested next steps

1. Keep this old repo as reference or archive.
2. Create a new clean repository named `aipetfeeder`.
3. Define MVP hardware list.
4. Create first OpenSCAD model for auger test module.
5. Print and test with real cat food.
6. Only after mechanical validation, design the full enclosure.

## Possible new project structure

```text
hardware/
  cad/
    openscad/
    freecad/
  stl/
  bom.md
firmware/
  platformio/
  esphome/
docs/
  project-notes.md
  architecture.md
  mechanical-tests.md
  wiring.md
```

## Important product direction

The competitive advantage should probably not be just "another automatic feeder".

The stronger direction is:

- open-source
- local-first
- Home Assistant friendly
- no mandatory cloud
- API controllable
- serviceable / printable parts

This can differentiate AiPetFeeder from many closed commercial smart feeders.

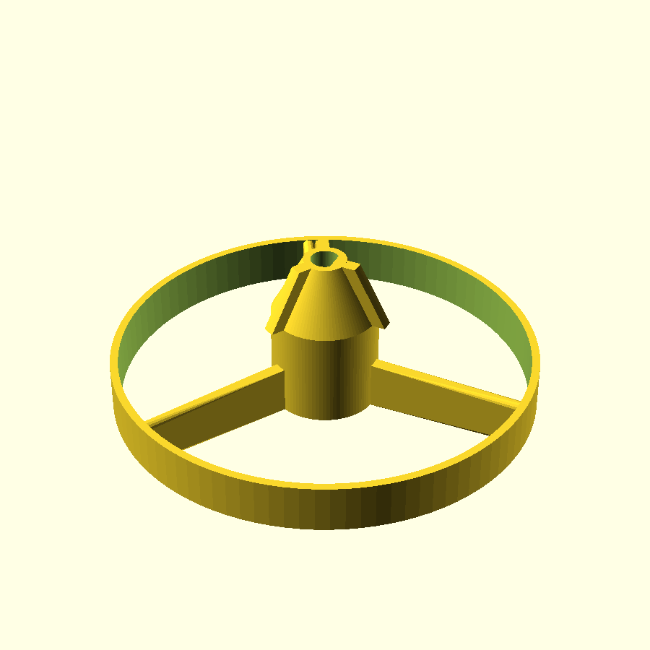
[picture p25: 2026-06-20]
hardware/renders/15_wheel_3q.png

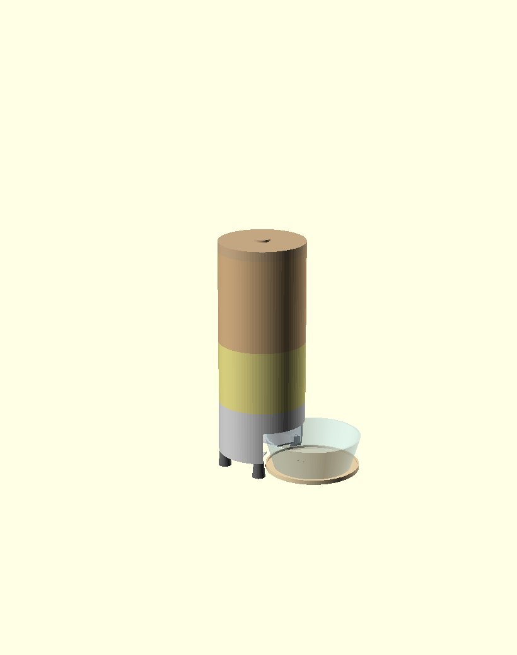
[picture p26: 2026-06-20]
hardware/renders/01_product_3q.png

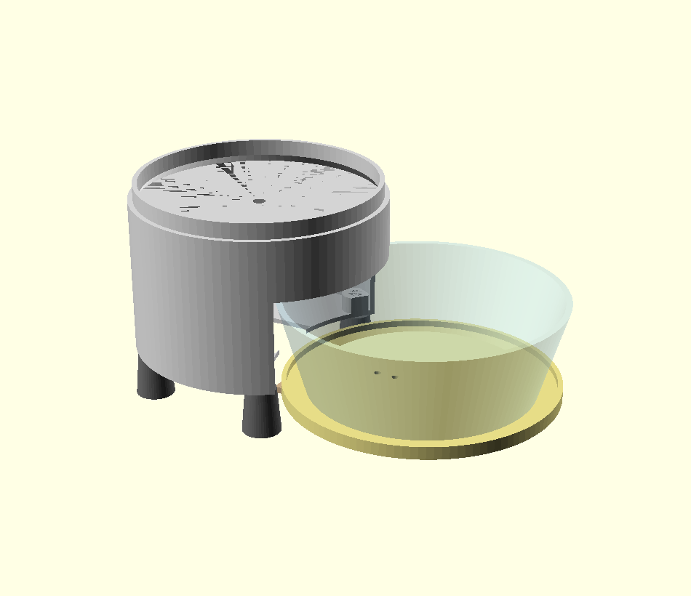
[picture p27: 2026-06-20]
hardware/renders/10_weighing_3q.png

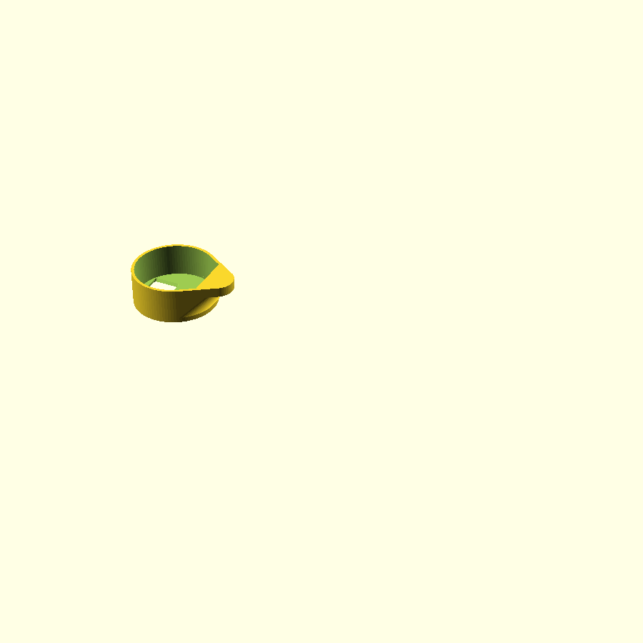
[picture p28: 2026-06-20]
hardware/renders/14_housing_3q.png

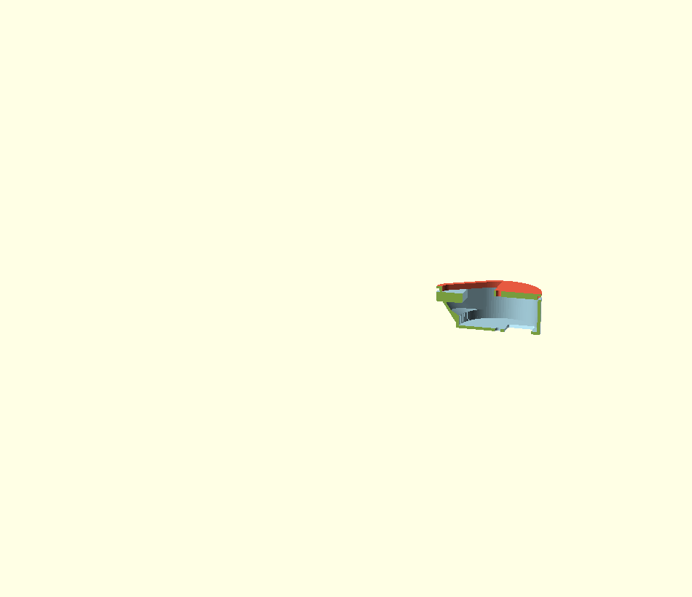
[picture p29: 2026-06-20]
hardware/renders/13_nest.png

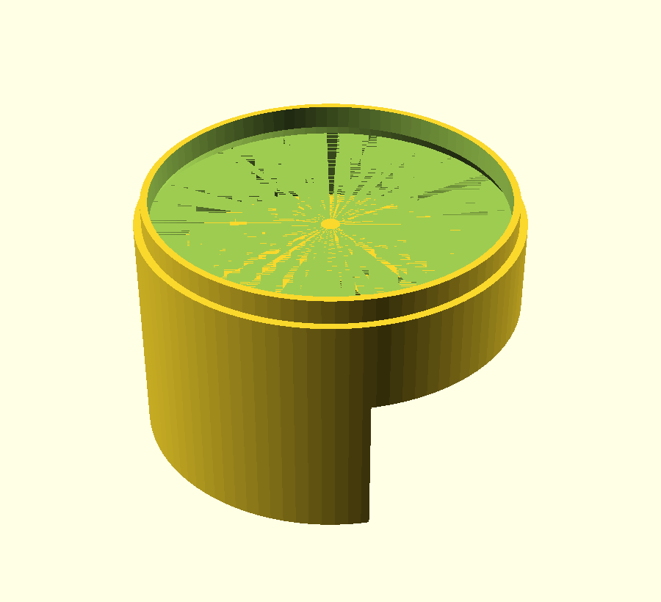
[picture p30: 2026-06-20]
hardware/renders/09_base_3q.png

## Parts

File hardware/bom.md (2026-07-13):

# Bill of Materials — AiPetFeeder

Status legend:

- ✅ **decided** — chosen, low risk
- 🧪 **to validate** — chosen as starting point, must be confirmed by a real test
- ❓ **open** — not yet decided, depends on test results

This BOM is split into two stages. **Build Stage 1 first.** Do not buy
Stage 2 parts until a feeding mechanism is validated (see
`docs/project-notes.md` → "Mechanical concept").

> **Stage 1 mechanism — decision 2026-05-20:** the **paddle wheel** is now
> the primary candidate. The auger remains as a **benchmark** to confirm
> (against real-world experience) that screw-and-kibble is unreliable for
> this application; both are printed and tested. Whichever wins on jam
> rate + portion repeatability survives into Stage 2.

---

## Stage 1 — Mechanism test modules

Goal: prove that the chosen mechanism actually moves dry cat food
reliably, without jamming, with a roughly repeatable portion. Nothing
else matters until this works.

| # | Part | Spec / note | Qty | Status |
|---|---|---|-----|---|
| 1 | Stepper motor NEMA17 | 17HS4401, 1.8°/step, ~40 N·cm. Torque reserve on purpose — food can compact. | 1 | 🧪 to validate (may downsize to short NEMA17 / NEMA14 later) |
| 2 | Stepper driver | A4988 or DRV8825 on a breakout. TMC2208 optional if noise matters. | 1 | 🧪 to validate |
| 3 | Microcontroller | ESP32 dev board (e.g. ESP32-WROOM DevKitC). Used only to spin the motor in Stage 1. | 1 | ✅ decided |
| 4 | Power supply | 12 V, ≥2 A DC for the stepper. Separate 5 V/USB for the ESP32. | 1 | 🧪 to validate (current draw under load is unknown) |
| 5a | **Paddle wheel** (primary) | 3D printed, parametric — `cad/openscad/paddle_wheel_module.scad`. Full-height hub + N paddles on the bottom half (sweep food along the floor). wheel_d **80**, thickness **18**, hub_d **20 mm**. **2026-06-05: ACTIVE STIRRER CONE on the hub top** — a frustum + 3 proud vanes (paddle continuations) under the (axle-ward) inlet; rotating, the vanes break any central arch + no flat surface for kibble to rest on. Portion set by **rotation count + HX711**, not pocket volume. Print cone-up (no supports). | 1–2 | 🧪 to validate |
| 5b | Paddle-wheel housing | 3D printed. **Lies on its flat floor.** Closed bottom with a rounded-rect OUTLET hole (**33×34 mm**, corner r=2, max on the Ø80 wheel); OPEN top; **4 flush rim MERLONS** (raised wall sections, within the wall OD) that key the cap (anti-rotation, prints support-free). Housing Ø **87.6 mm** × **37 mm**. | 1 | 🧪 to validate |
| 5c | Paddle-wheel end cap | 3D printed, removable lid. Drops onto the housing rim; **4 edge NOTCHES** that the housing merlons poke through (anti-rotation, 4 index positions, no protruding features, no supports). Central axle bore + radial-offset INLET hole (**33×34 mm rounded, extended toward the axle**) + **COLLAR** (low rectangular fence) on top of the cap that retains the hopper laterally (collar-mount, no socket — see ADR `2026-05-25-collar-mount-hopper-redesign`). | 1 | 🧪 to validate |
| 6a | Auger (benchmark) | 3D printed, parametric — `cad/openscad/feeder_test_module.scad`. Expected to jam per real-world experience; tested only to confirm. | 1 | 🧪 benchmark |
| 6b | Auger barrel (benchmark) | 3D printed, paired with the auger. | 1 | 🧪 benchmark |
| 7 | Drive axle | Ø5 mm rod, D-flat keys it (both wheel and auger have matching D-bore). **Steel rod preferred** — printed axles flex/wear. | 1 | 🧪 to validate |
| 7b | Motor coupler | 5 mm rigid/flex coupler: axle rear stub → NEMA17 5 mm shaft. | 1 | 🧪 to validate |
| 8a | Test hopper (small) | 3D printed, parametric — `paddle_wheel_module.scad part="hopper"`. Round Ø70 top → rect open bottom matching the cap inlet hole. **No spout walls** (collar-mount, sits ON the cap). | 1 | ✅ decided |
| 8b | **Bulk hopper — funnel** | 3D printed, parametric — `bulk_hopper_module.scad part="funnel"`. Ø160 round top × **115 mm** tall, narrows to **rect bottom matching the cap inlet hole (33×34 rounded)**. Cone is **more open (~36° from vertical)** with a **straight Ø160 cylinder above** — bigger throat + wider approach to reduce arching. Primary active anti-bridge is now the **wheel's stirrer cone** (5a); a **vibromotor** is still planned but its mount is TBD (removed for now, re-added with the real motor). **No spider, no spout walls** (collar-mount). **Print right-side up — rect plug on the bed, lip up.** | 1 | 🧪 to validate |
| 8c | **Bulk hopper — storage ring** | 3D printed, parametric — `bulk_hopper_module.scad part="ring"`. Ø160 × **150** mm (printed part is 160 mm with its stacking lip — 170 would have been 180 mm = the whole bed, no brim margin). Print **1** for ~1.5 kg total capacity (funnel 0.9 L + ring 2.79 L = 3.69 L × 0.4 g/mL), **2** for ~2.6 kg. Modular — print one extra ring to recover the old volume. Stackable slip-fit lip. | 1+ | 🧪 to validate |
| 8d | **Bulk hopper — lid** | 3D printed, parametric — `bulk_hopper_module.scad part="lid"`. Wraps the topmost ring lip; finger pad on top. | 1 | 🧪 to validate |
| 9a | **Lower body chassis** | ~~`chassis_module.scad`~~ **DEPRECATED / archived** (`archive/chassis_module.scad`). The body is now the Ø160 cylinder tower: `bulk_hopper_module.scad` `base_motor` + `base_hopper` (2 snap-locked parts) standing FLAT on its own sole (form 1a — the screw-in legs and the external weighing station were removed 2026-07-13). Electronics live in the base annulus: `el_tray` (vertical, on rails) + `el_panel` (service window, DC jack + USB). Feeding: a shallow pull-out `tray` (Ø150 × 16, ~280 ml) rides `cell_platform` on the load cell, in the front scallop. | — | ✅ superseded |
| 9 | Dry cat food | The actual food the cat eats. Kibble size/shape changes everything — test with the real thing. | — | ✅ decided |
| 10 | Misc | M3 screws/heat-set inserts for motor mount, jumper wires, breadboard. | — | ✅ decided |

Anti-bridge (now part of the design, not optional):

| # | Part | Spec / note | Qty | Status |
|---|---|---|-----|---|
| 11 | **Vibration motor** | Small **coin ERM** (e.g. Ø10×3.4 mm) or cylindrical pager motor, mounted on the funnel's external pad near the throat. **Active anti-bridge** — pulsed during dispense (replaces the removed passive spider). **Exact motor TBD** → drives the final mount geometry. | 1 | 🧪 to validate (need motor spec to finalize pad) |
| 11b | Motor driver | Logic-level **MOSFET** (e.g. AO3400/2N7000-class) + **flyback diode** (1N4148/Schottky) across the motor, driven from an ESP32 GPIO. | 1 | ✅ decided |

---

## Stage 2 — Full prototype (only after Stage 1 passes)

| # | Part | Spec / note | Qty | Status |
|---|---|---|-----|---|
| 1 | Load cell | 1–5 kg bar load cell, for closed-loop portion control by weight. | 1 | 🧪 to validate (range depends on bowl + portion size) |
| 2 | HX711 | 24-bit ADC amplifier board for the load cell. | 1 | ✅ decided |
| 3 | Button | Momentary push button, "feed one portion". INPUT_PULLUP. | 1 | ✅ decided |
| 4 | Display | TM1637 4-digit 7-seg, or small OLED. Shows last feed / weight / status. | 1 | ❓ open (nice-to-have, not MVP-critical) |
| 5 | Enclosure | Printed, serviceable, separate from the validated auger module. | 1 | ❓ open (design last) |

### Explicitly dropped

- **HC-06 Bluetooth** — not needed. ESP32 has Wi-Fi; config goes over
  local API / Home Assistant. (Per `docs/project-notes.md`.)
- **Cloud dependency** — out of scope by design: local-first.

---

## Open questions to resolve via Stage 1 test

- **Paddle wheel:** pocket count and pocket volume that give one
  acceptable portion per fraction of a rotation? Does any kibble jam
  in the inlet boss, the wheel cavity, or the chute?
- **Auger (benchmark):** does it confirm the expected jam behaviour
  (or surprise us)? Anti-jam reverse stepping needed?
- Portion repeatability good enough for open-loop, or is the HX711
  weight loop mandatory anyway?
- Is NEMA17 17HS4401 overkill → can we downsize (cost, size, power)?
  (Paddle wheel torque requirement is much lower than auger.)

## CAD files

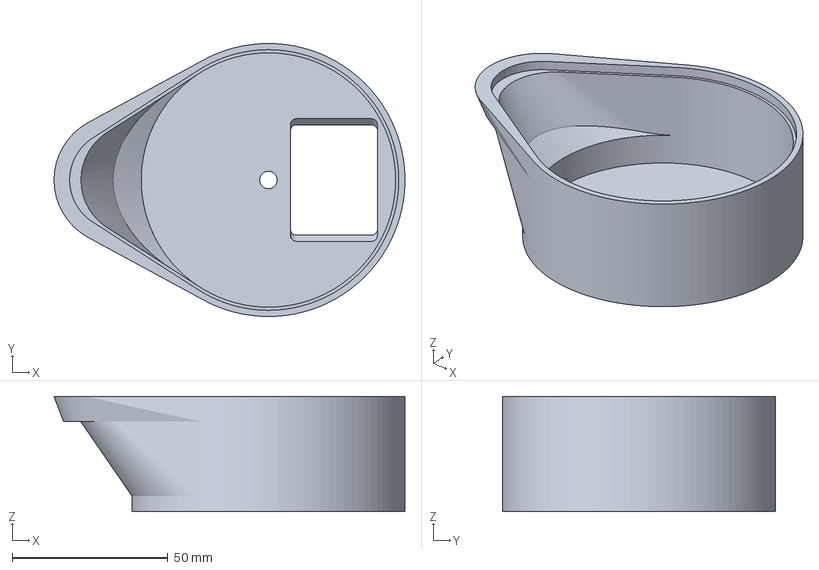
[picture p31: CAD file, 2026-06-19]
hardware/3mf/pw_housing.3mf
112.6 x 87.6 x 37.0 mm

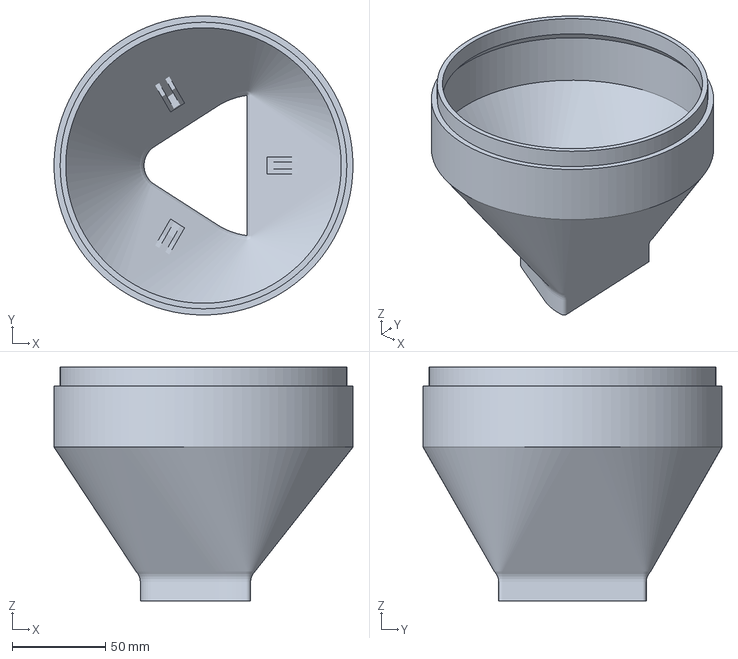
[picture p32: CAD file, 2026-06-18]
hardware/3mf/bh_funnel.3mf
160.0 x 160.0 x 125.0 mm

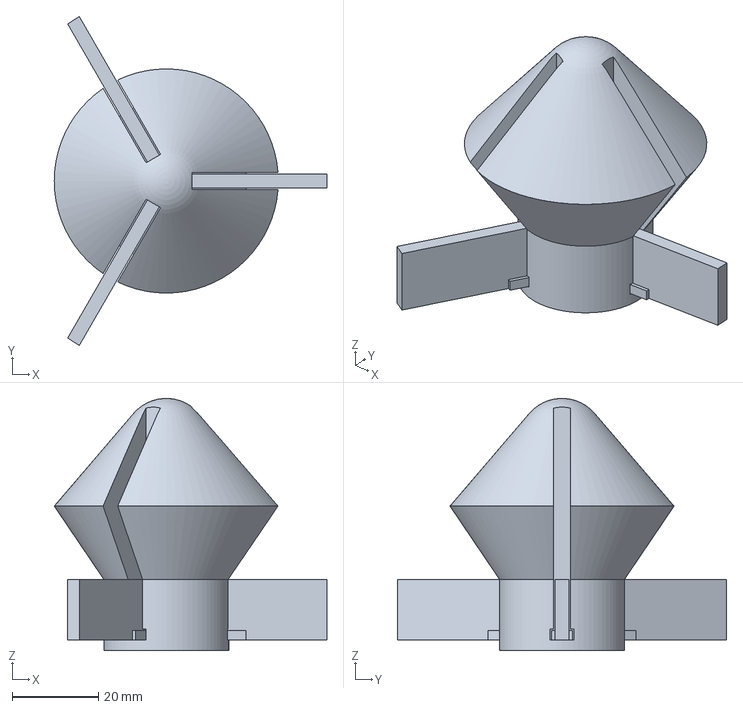
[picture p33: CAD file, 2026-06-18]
hardware/3mf/bh_spider.3mf
63.2 x 76.3 x 58.5 mm

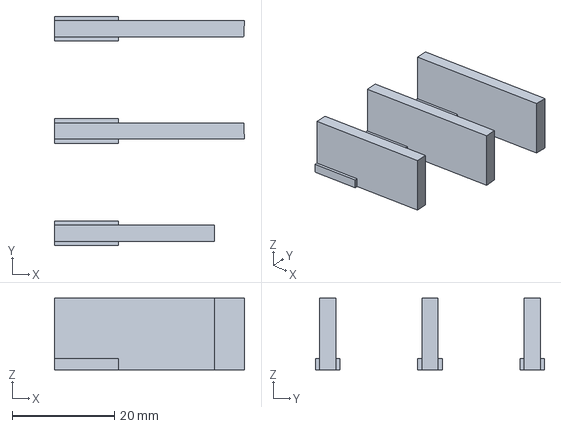
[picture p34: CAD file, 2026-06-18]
hardware/3mf/bh_spider_legs.3mf
37.1 x 44.8 x 14.0 mm

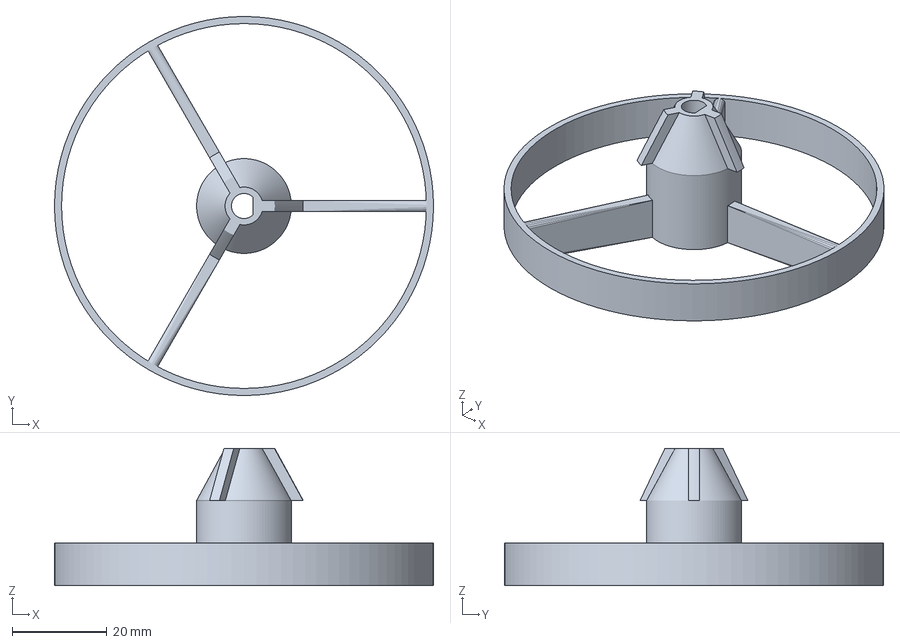
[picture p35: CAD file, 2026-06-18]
hardware/3mf/pw_wheel.3mf
80.0 x 80.0 x 29.0 mm

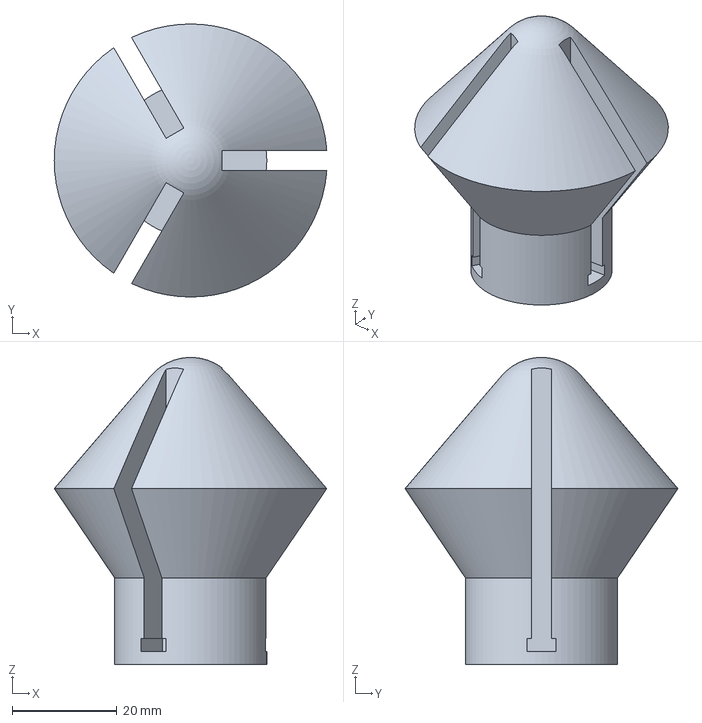
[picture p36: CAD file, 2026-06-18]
hardware/3mf/bh_spider_body.3mf
51.9 x 52.0 x 58.5 mm

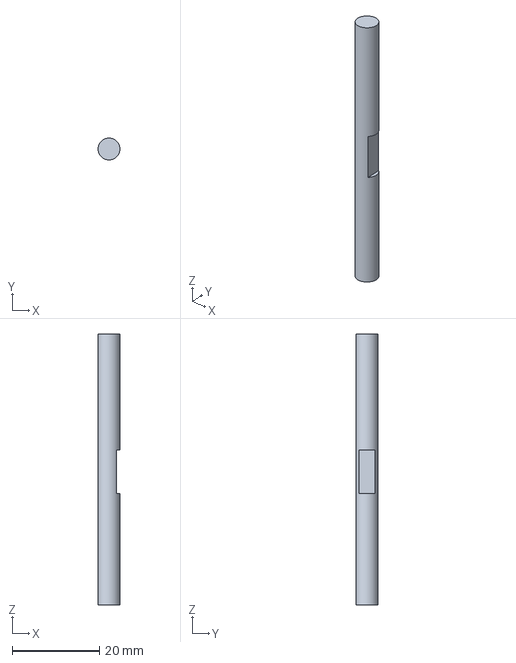
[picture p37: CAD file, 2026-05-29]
hardware/3mf/pw_axle.3mf
5.00 x 5.00 x 62.0 mm

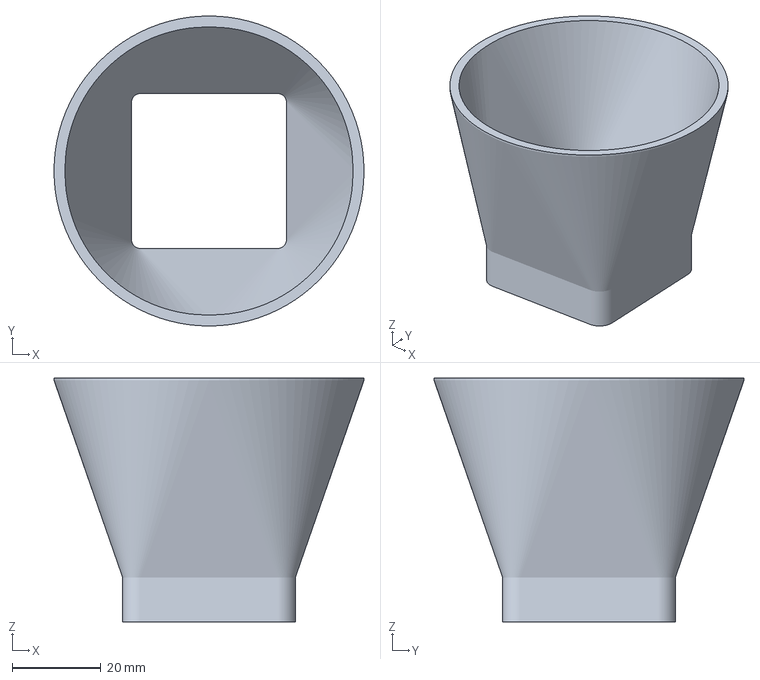
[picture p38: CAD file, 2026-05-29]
hardware/3mf/pw_hopper.3mf
70.0 x 70.0 x 55.0 mm

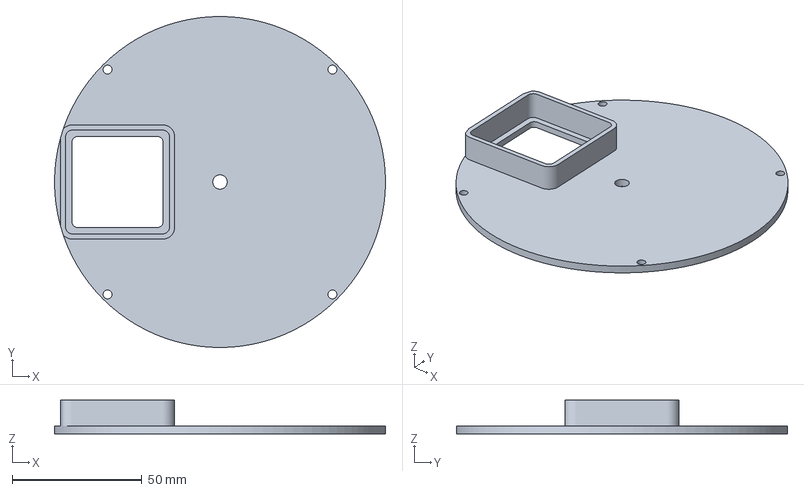
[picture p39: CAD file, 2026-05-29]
hardware/3mf/pw_end_cap.3mf
127.6 x 127.6 x 13.0 mm

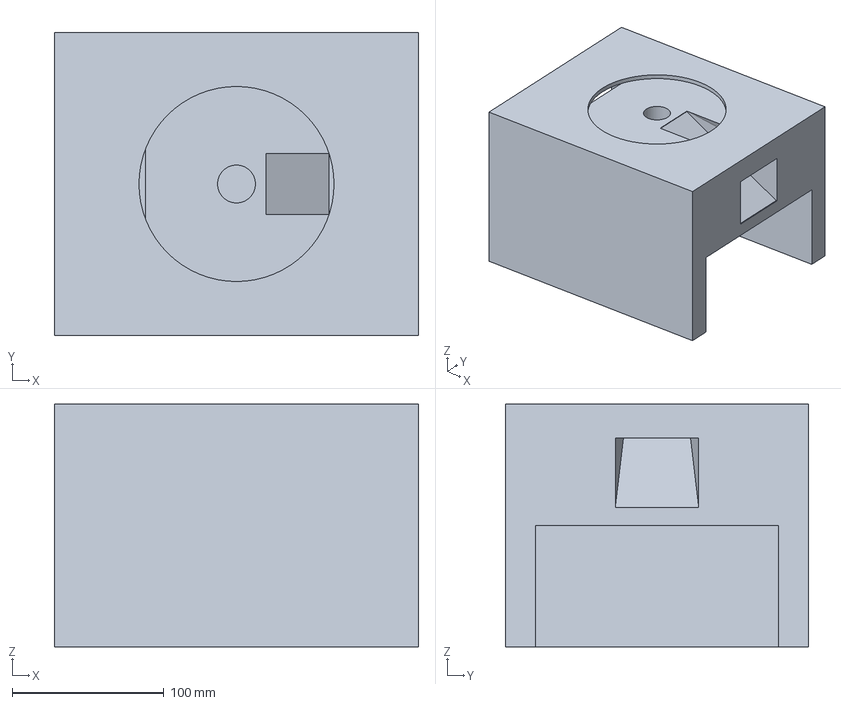
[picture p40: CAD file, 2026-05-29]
hardware/3mf/chassis.3mf
240.0 x 200.0 x 160.0 mm

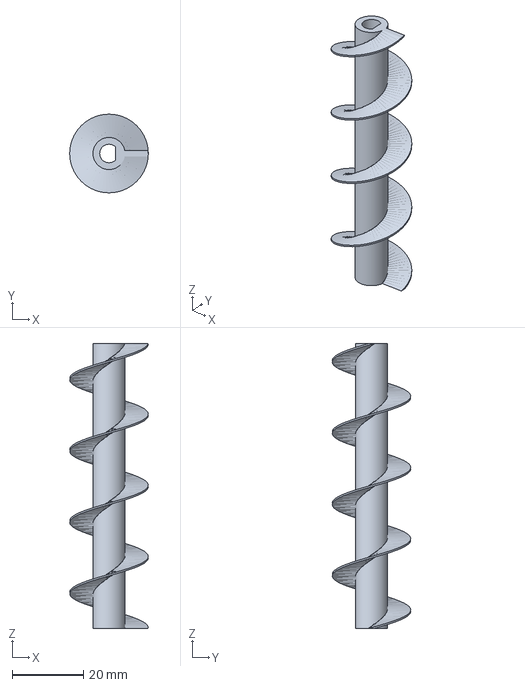
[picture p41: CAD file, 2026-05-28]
hardware/3mf/auger.3mf
22.0 x 22.0 x 80.0 mm

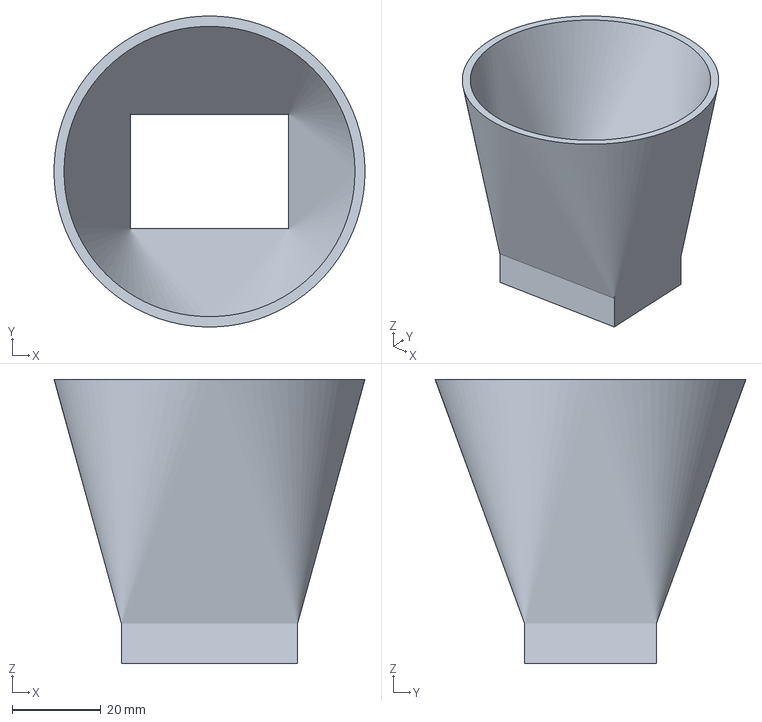
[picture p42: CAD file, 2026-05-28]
hardware/3mf/hopper.3mf
70.0 x 70.0 x 64.0 mm

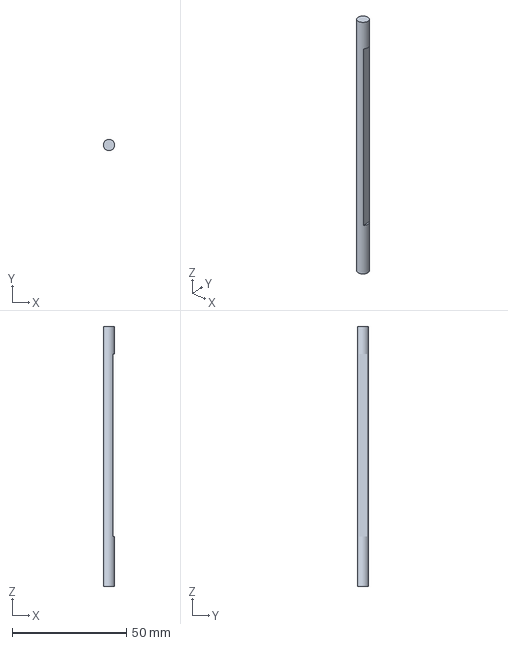
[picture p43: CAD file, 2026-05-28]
hardware/3mf/axle.3mf
5.00 x 5.00 x 114.0 mm

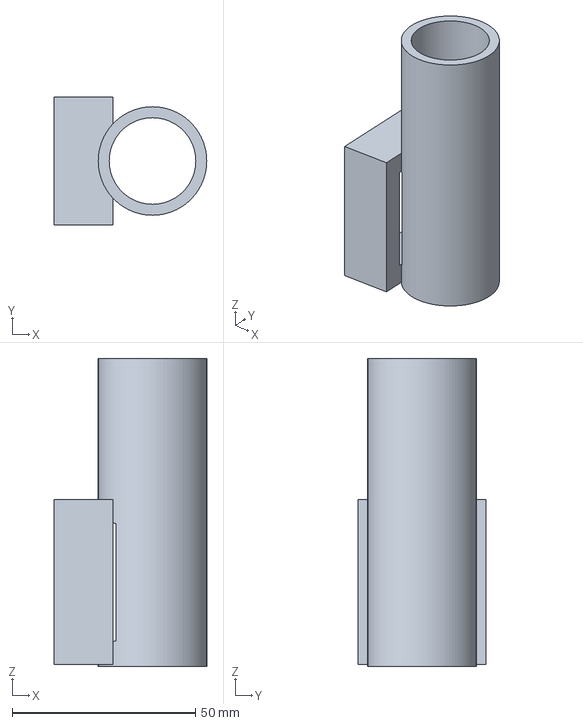
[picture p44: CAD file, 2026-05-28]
hardware/3mf/barrel.3mf
41.6 x 35.0 x 84.0 mm

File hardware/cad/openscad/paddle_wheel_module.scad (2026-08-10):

// AiPetFeeder — Paddle-wheel rotary-disc dispenser
// ---------------------------------------------------------------------------
// Rewrite 2026-05-25: COLLAR-MOUNT hopper redesign per ADR
// `2026-05-25-collar-mount-hopper-redesign`. Hopper no longer plugs INTO a
// socket — it sits ON TOP of the cap, retained laterally by a low collar
// (fence) that surrounds its outer bottom edge. Kibble flow pipe has no
// wall narrowing and no shelf — the cap inlet hole IS the narrowest cross-
// section in the entire pipe.
//
// Architecture summary (unchanged from previous revision):
// Housing rests on its FLAT circular floor (axle vertical in operation).
// Inlet through the cap (rounded-rect hole at a radial offset). Outlet
// through the floor (same shape hole, 180° apart angularly). Paddles fill
// only the BOTTOM half of the cavity — they sweep kibble along the floor
// from inlet position to outlet position.
//
//        ┌──────────────────────────┐
//        │     hopper / funnel      │     (sits ON TOP of cap;
//        │     (open bottom)        │      no spout into a socket)
//        └────────────┬─────────────┘
//                     │ flow area = hole size (no walls)
//                     │
//        ╔═══╦════════│════════════╦══╗   ← collar walls (fence)
//        ║   ╠════════╧════════════╣  ║      surrounding the hopper
//        ╞═══╧═══════════════════════╡   ← cap_plate (in bulk_hopper_module)
//        │     ░░░░░░░░░░░░░░░░░░   │      cavity
//        │  ┌──┐  ┌──┐  ┌──┐ (3×)   │      paddles (bottom half only)
//        ├──┤  ├──┤  ├──┤           │      n_paddles = 3, sweep floor
//        ├──┘  └──┴──┘  └───────────┤      housing floor
//                  │  outlet hole
//                  ▼ → chute → bowl
//
// Parts:
//   part = "wheel"    -> hub + half-height paddles + D-bore
//   part = "axle"     -> through axle
//   part = "housing"  -> cup, floor with outlet hole (rounded corners)
//   part = "hopper"   -> small test hopper, open-bottom rect-to-round cone
//   part = "assembly" -> all stacked together for fit check
// ===========================================================================

part = "assembly";   // wheel | axle | housing | hopper | assembly

/* [Wheel] */
// 2026-06-03: scaled BACK to wheel_d=80 (was 120). The Ø120 upscale
// existed only to fight bridging passively; we're switching to an ACTIVE
// anti-bridge (vibromotor on the funnel) + HX711 closed-loop, so the big
// wheel is no longer needed and the whole mechanism shrinks. Portion is
// now set by rotation count, not pocket volume.
wheel_d         = 80;    // outer diameter (over paddle tips)
wheel_thickness = 18;    // axial extent of wheel hub (taller again — the
                         //   pocket area shrank with the smaller wheel)
n_paddles       = 3;     // sector 120°
paddle_thick    = 2.4;
paddle_fraction = 0.5;
rim_t           = 1.5;   // thin RING along the outer contour tying the 3 paddle
                         //   tips together (0 = no ring). Same radius/height as
                         //   the paddle tips, so it keeps the housing clearance.
hub_d           = 20;    // proportional to wheel_d=80

/* [Active stirrer cone] (2026-06-05, replaces the dead static spider) */
// A frustum on the hub TOP, under the (now bigger, axle-ward) cap inlet.
// 3 proud VANES (continuations of the paddles) ride the cone — because
// they ROTATE with the wheel, they poke/break any arch forming over the
// centre. Kibble also can't rest on a flat top: it slides into pockets.
cone_h        = 11;      // cone height above the hub (clears the cap ~4.5 mm)
cone_top_d    = 8;       // truncated tip Ø (solid above the axle)
vane_proud    = 2.5;     // how far the vanes stand proud of the cone
vane_t        = paddle_thick;  // vane thickness = paddle thickness

/* [Axle] */
axle_d         = 5.0;
axle_flat      = 0.8;
axle_stub_top  = 8;
axle_stub_bot  = 22;
fit_clear      = 0.30;

/* [Housing] */
housing_clear      = 0.8;
wheel_axial_clear  = 0.5;
floor_clear        = 0.5;
housing_wall       = 3;
end_wall           = 3;
// 2026-05-29: kibble settling buffer between the wheel TOP and the cap
// INLET. Before this was implicit 0 mm — kibble dropping through the
// cap inlet had no room to spread before hitting the wheel. 15 mm =
// one full kibble (~12 mm) plus clearance; multiple pieces can
// pre-stack in the buffer and settle into pockets as they pass under
// the inlet.
housing_buffer_h   = 15;

/* [TEARDROP top] — round bottom (wheel) flares to a teardrop top + cap */
// 2026-06-06: user test — the funnel with the biggest opening flows best.
// To make the cap inlet bigger, the housing stays ROUND at the bottom
// (where the round wheel turns) and flares to a TEARDROP at the top, the
// tip pointing BACK toward the inlet/funnel. The cap is the same teardrop
// and seats only one way → the SHAPE itself keys the cap (anti-rotation),
// so the old (snapping) merlons are GONE.
td_back    = 22;        // teardrop tip reach beyond hr_out, toward the inlet
// 2026-06-20 — tip BLUNTED 18→26. The reach (= hr_out + td_back) is invariant of
// tip_r, so the inlet opening is unchanged toward the funnel — but a fatter tip
// has no thin overhanging point to pinhole, so the old inward nose_fill (which
// capped the tip opening) is GONE. Mirror pw_td_tip_r in bulk_hopper_module.scad.
td_tip_r   = 26;        // teardrop tip radius (blunt → prints clean, no fill)
td_flare_z = 5;         // z where the round→teardrop flare starts (above recess)
// FEED RAMP filling the teardrop-tip lobe. Without it the lobe floor is a flat
// shelf at td_flare_z, BELOW the wheel rim/paddle top — kibble lands there, can't
// get over the rim into a sector, and the spinning rim grinds it → JAM. The ramp
// raises that shelf into a slope: low at the wheel edge (just over the rim top)
// rising to the tip, so kibble slides over the rim into the wheel. (No housing
// height increase.)
ramp_lo    = 13;        // ramp top at the wheel edge (≈ rim top 12.5 + 0.5)
ramp_hi    = 32;        // ramp top at the teardrop tip (< wheel cone top 32.5)
// 2026-06-19 — the teardrop nose tapered to a thin overhanging point that
// printed with a hole; an inward nose_fill closed it but CAPPED the tip of the
// inlet (shrinking the very opening the teardrop was meant to enlarge). 2026-06-20
// — replaced by BLUNTING the tip (td_tip_r 18→26): no thin point to pinhole, full
// opening kept. The housing still prints ROTATED 180° about Z (render dispatch).
td_clear   = 0.4;       // (legacy) cap-over-housing teardrop slip clearance
// Funnel NEST (replaces the old cap rebate, since the cap is now MERGED into the
// funnel). The funnel's cap-plate drops a teardrop SKIRT over the housing top
// rim → self-centres + anti-rotates (the teardrop shape keys it). Matching
// params live in bulk_hopper_module.scad (nest_clear / skirt_wall / nest_depth).
nest_clear = 0.4;       // skirt-over-rim slip clearance (mirror in the funnel)
// td_tip_cx is derived below (needs hr_out)

/* [Cap inlet] — big opening on the INLET (back) side, reaching the axle.
   It hugs the teardrop cavity (no rectangle) but stops at the axle: the
   FRONT of the cap (over the floor outlet) stays solid, with the axle
   bore. The OUTLET (floor) keeps the hole_* params. */
inlet_margin = 3;       // rim between the inlet edge and the cavity wall
axle_keep    = axle_d/2 + fit_clear + 2;  // solid cap kept around the axle bore

// (Cap rebate joint params rab_d/rab_w/cap_clear REMOVED 2026-07-02 — the housing
//  rebate went away 2026-06-19 and end_cap with it; nothing referenced them.)
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

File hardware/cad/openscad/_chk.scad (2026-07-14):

// Interference / fit checks. MUST live NEXT TO the module: include<> resolves relative to
// the INCLUDING FILE, not the cwd — a check file in /tmp silently gets undef everything
// and every intersection comes out empty, which reads as "clear". It bit me once.
include <bulk_hopper_module.scad>
use <paddle_wheel_module.scad>
part = "none";
chk = "";
module tabs(rot=0) rotate([0,0,rot]) translate([0,0,base_h]) for(i=[0:bay_n-1]) bay_tab(i);

// --- form-1a fit (RE-RUN: the originals were run from /tmp and were bogus) ---
if (chk=="tray_motor")  intersection() { tray_mounted(); base_motor(); }
if (chk=="tray_disc")   intersection() { tray_mounted(); base_hopper(); }
if (chk=="plat_motor")  intersection() { cell_platform(); base_motor(); }
if (chk=="cell_nema")   intersection() { cell_mock(); motor_mock(base_deck_z); }
if (chk=="ped_nema")    intersection() { cell_pedestal(); motor_mock(base_deck_z); }
if (chk=="sole_nema")   intersection() { base_sole(); motor_mock(base_deck_z); }
if (chk=="tray_eltray") intersection() { tray_mounted(); el_tray_mounted(); }
if (chk=="eltray_motor")intersection() { el_tray_mounted(); base_motor(); }
if (chk=="panel_motor") intersection() { el_panel(); base_motor(); }
if (chk=="eltray_nema") intersection() { el_tray_mounted(); motor_mock(base_deck_z); }

// --- J2 bayonet ---
if (chk=="bay_entry")   intersection() { base_hopper(); tabs(0); }          // want EMPTY
if (chk=="bay_locktab") intersection() { base_hopper(); tabs(-bay_run); }   // want EMPTY
if (chk=="bay_lockover")                                                    // want NON-empty
    intersection() {
        base_hopper();
        rotate([0,0,-bay_run]) translate([0,0,base_h]) for(i=[0:bay_n-1])
            rotate([0,0,i*360/bay_n]) rotate_extrude(angle=bay_tab_ang, $fn=160)
                translate([bay_tab_ir, bay_tab_z+bay_tab_h+bay_slip]) square([bay_tab_r, 3]);
    }
if (chk=="bay_detent")  intersection() { base_hopper(); tabs(-bay_run/2); } // want NON-empty
if (chk=="shell_lip")   intersection() { translate([0,0,base_h]) funnel_shell(); base_hopper(); }
// J4 detents attached to cap? intersect the detent band with the rest of the cap
if(chk=="cap_nestdet") intersection() {
    cap_plate();
    translate([0,0,nest_h-1.4]) linear_extrude(0.7)
        difference() { offset(nest_clear) teardrop_2d(pw_hr_out,pw_td_tip_r,pw_td_tip_cx);
                       offset(nest_clear-nest_det) teardrop_2d(pw_hr_out,pw_td_tip_r,pw_td_tip_cx); }
}

// --- L1 lid bayonet onto the ring lip ---
module lid_tabs(rot=0) rotate([0,0,rot]) translate([0,0,ring_h]) for(i=[0:bay_n-1]) bay_tab_lid(i);
if(chk=="lid_entry")  intersection() { ring(); lid_tabs(0); }         // want EMPTY (tab in channel)
if(chk=="lid_locktab")intersection() { ring(); lid_tabs(-bay_run); }  // want EMPTY (tab in the run)
if(chk=="lid_lockover")                                               // want NON-empty (roof over tab)
    intersection() {
        ring();
        rotate([0,0,-bay_run]) translate([0,0,ring_h]) for(i=[0:bay_n-1])
            rotate([0,0,i*360/bay_n]) rotate_extrude(angle=bay_tab_ang, $fn=160)
                translate([bay_tab_ir, bay_tab_z+bay_tab_h+bay_slip]) square([bay_tab_r, 3]);
    }

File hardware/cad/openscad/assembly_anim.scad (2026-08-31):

// Assembly animation for the form-1a tower — FULL build order, electronics included.
// Each part flies from an exploded approach offset into its SEATED pose along the
// insertion vector that run_sweep.sh actually swept for collisions, so the motion in
// this video is the motion that was proven clear, not a plausible-looking guess.
//
// TWO RENDER PATHS, same timing and the same colour table:
//   modules (default)  — reads the live model; correct geometry, but OpenSCAD's OpenCSG
//                        preview hatches base_motor's deck badly (cut planes coplanar
//                        with faces). Fine for checking poses in the GUI.
//   meshes  (mesh_dir) — imports the p_<name>.stl the clash harness already baked in
//                        their seated global poses. No CSG left to preview, so no
//                        hatching. THIS is what the video frames are rendered from.
//
//   xvfb-run -a openscad -o f.png --imgsize=900,680 --camera=0,0,90,68,0,0,620 \
//       -D '$t=0.30' -D 'mesh_dir="/path/to/asm"' assembly_anim.scad
//
// part="__h__" is the sentinel that keeps the included file's own dispatch silent.
// The camera is FIXED per frame by the driver; the scene turns instead (see view_ang),
// so whatever is being fitted faces the viewer: service side (-X, electronics + power)
// for the bay work, front (+X, the scallop) for the feed tray.
include <bulk_hopper_module.scad>
part = "__h__";
$fn = 48;                     // preview density; plenty for a motion video
mesh_dir = "";                // "" = build from modules; else dir holding p_<name>.stl

// cosine ease-in-out: 0 before window a, 1 after window b, smooth between.
function prog(a,b) = $t <= a ? 0 : $t >= b ? 1 : (0.5 - 0.5*cos(180*($t-a)/(b-a)));

// One colour table for both render paths, so they can't drift.
COL = [["base_motor",   "Gainsboro"],   ["motor",       "#2b2b2b"],
       ["cell",         "DimGray"],     ["cell_platform","Wheat"],
       ["el_tray",      "SteelBlue"],   ["boards",      "DarkGreen"],
       ["el_panel",     "Tomato"],      ["dc_jack",     "#1a1a1a"],
       ["base_hopper",  "Gold"],        ["housing",     "LightSteelBlue"],
       ["wheel",        "Silver"],      ["cap",         "MediumSeaGreen"],
       ["cone",         "Orange"],      ["shell",       "Khaki"],
       ["spider",       "MediumPurple"],["ring",        "BurlyWood"],
       ["lid_on_ring",  "Tan"],         ["tray",        "LightBlue"],
       ["dc_plug",      "#111111"],     ["usb_plug",    "#222222"]];
function col(n) = COL[search([n], COL)[0]][1];

// The funnel tube is the only thing that has to be see-through: the cone and the spider
// go in AFTER it, so an opaque shell would hide both. Everything else reads fine solid —
// the leg shroud is still open at the top while the bay is being populated.
function alp(n) = (n == "shell" && $t < 0.78) ? 0.32 : 1;

// --- seated global poses. Authoritative source is clash_harness.scad's A(): the same
// poses are what the swept-path check used, so the two files must not drift apart. ---
module G(name) {
    if      (name == "base_motor")    base_motor();
    else if (name == "motor")         motor_mock(base_deck_z);
    else if (name == "cell")          cell_mock();
    else if (name == "cell_platform") cell_platform();
    else if (name == "el_tray")       el_tray_mounted();
    else if (name == "boards")        el_boards_mounted();
    else if (name == "el_panel")      el_panel();
    else if (name == "dc_jack")       dc_jack_mock();
    else if (name == "dc_plug")       dc_plug_mock();
    else if (name == "usb_plug")      usb_plug_mock();
    else if (name == "base_hopper")   base_hopper();
    else if (name == "housing")       translate([0,0,base_motor_h])                   housing();
    else if (name == "wheel")         translate([throat_cx,0,base_motor_h + 3.5])     wheel();
    else if (name == "cap")           translate([0,0,base_h - nest_h])                cap_plate();
    else if (name == "cone")          translate([0,0,base_h + cap_t - nest_h])        funnel_cone();
    else if (name == "shell")         translate([0,0,base_h])                         funnel_shell();
    else if (name == "spider")        translate([0,0,base_h + cap_t - nest_h])        spider();
    else if (name == "ring")          translate([0,0,base_h + z_funnel_top])          ring();
    else if (name == "lid_on_ring")   translate([0,0,base_h + z_funnel_top + ring_h]) lid();
    else if (name == "tray")          tray_mounted();
}

module A(name)
    color(col(name), alp(name)) {
        if (mesh_dir != "") import(str(mesh_dir, "/p_", name, ".stl"));
        else                G(name);
    }

// place `name`: HIDDEN until its window opens at `a`, then slides from the approach
// offset (ox,oy,oz) into its seat across [a,b]. Progressive build — only the in-flight
// part is aloft, everything earlier is already seated.
module place(name, ox,oy,oz, a,b) {
    if ($t >= a) {
        p = prog(a,b);
        translate([ox*(1-p), oy*(1-p), oz*(1-p)]) A(name);
    }
}

// Scene spin, so whatever is being fitted faces the viewer. Verified by rendering the
// base + panel + platform at 0 and 90 and looking:
//   90  = service window (electronics, power) toward the camera
//   270 = front scallop (feed tray) toward the camera
//
// This MUST be a function called from inside rotate(), not a top-level variable.
// $t arrives via -D, and OpenSCAD does not have it in scope during the top-level
// ASSIGNMENT pass — `view_ang = ...*prog($t...)` silently evaluated as if $t were 0,
// so the scene never turned while the parts animated correctly (they are guarded
// inside module instantiations, where $t is live). Same trap for anything else
// derived from $t outside a module.
// Each turn is timed so the part being fitted is roughly face-on when it seats.
function view_ang() =
      270                               // front-on: the niche, the load cell, the bowl platform
    + 180*prog(0.20, 0.28)              // swing to the service side for the electronics bay
    + 180*prog(0.80, 0.89)              // back to the front for the feed tray
    + 180*prog(0.955, 0.975);           // and round again to end on the power lead

rotate([0, 0, view_ang()]) {
    A("base_motor");                                        // ground — static

    // --- 1. inside the leg shroud: motor, weighing, electronics bay ---
    place("motor",          0,  0, -70,   0.05, 0.11);      // NEMA17 enters from BELOW
    // The weighing pair comes in from the FRONT (+X), not straight down. Both cantilever
    // past the Ø160 base (cell to x=105, platform to x=158) and the tray they carry slides
    // out +X, so a drop was never the real motion — and the sweep agrees: dropped, they
    // clip the base rim (103 / 606 mm3); slid in +X, the platform is 0.0 mm3 at every
    // sample. The cell still scrapes a 1 mm sill on the way (38.9 mm3, see the report) —
    // that is a seated-fit defect, constant along the path, not a blocked corridor.
    place("cell",          60,  0,   0,   0.11, 0.16);      // load cell onto its pedestal
    place("cell_platform", 60,  0,   0,   0.16, 0.21);      // weighing platform onto the cell
    // ORDER MATTERS HERE, and it is the opposite of what it was. The service panel is
    // fitted from inside and pushed outward; seated it is clear of both the tray and the
    // boards (EMPTY against each), but MID-PATH it passes 2182.9 mm3 straight through
    // el_tray. Nothing is wrong with either part's geometry — the panel simply has no
    // corridor once the tray is in. So the panel goes in first, then its jack, then the
    // tray drops in behind them. A swept-path check found this; a seated check never would.
    place("el_panel",      27,  0,   0,   0.21, 0.26);      // panel fitted from INSIDE, outward
    place("dc_jack",       20,  0,   0,   0.26, 0.30);      // barrel jack through the panel
    place("el_tray",        0,  0,  60,   0.30, 0.36);      // tray drops down the wall rails
    place("boards",         0,  0,  60,   0.30, 0.36);      // boards ride the tray in

    // --- 2. the dosing stack ---
    place("base_hopper",    0,  0,  70,   0.36, 0.42);      // core disc caps the bay
    place("housing",        0,  0,  80,   0.42, 0.48);      // paddle housing over the centre
    place("wheel",          0,  0,  80,   0.48, 0.53);      // dosing wheel INTO the housing
    place("cap",            0,  0,  80,   0.53, 0.58);      // cap plate onto the housing top
    place("cone",           0,  0,  75,   0.58, 0.64);      // mass-flow cone onto the cap
    place("shell",          0,  0,  85,   0.64, 0.70);      // big tube down over the cone
    place("spider",         0,  0,  75,   0.70, 0.76);      // anti-pressure spider into pockets
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

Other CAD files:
hardware/3mf/bh_lid.3mf
hardware/3mf/bh_ring.3mf
hardware/cad/openscad/base_stub.scad
hardware/cad/openscad/archive/chassis_module.scad
hardware/cad/openscad/bulk_hopper_module.scad
hardware/cad/openscad/chassis_module.scad
hardware/cad/openscad/clash_harness.scad
hardware/cad/openscad/feeder_test_module.scad
hardware/cad/openscad/gallery_views.scad
hardware/cad/openscad/ring_stub.scad
hardware/stl/auger.stl
hardware/stl/axle.stl
hardware/stl/barrel.stl
hardware/stl/bh_funnel.stl
hardware/stl/bh_lid.stl
hardware/stl/bh_ring.stl
hardware/stl/bh_spider_body.stl
hardware/stl/bh_spider_legs.stl
hardware/stl/chassis.stl
hardware/stl/hopper.stl
hardware/stl/pw_axle.stl
hardware/stl/pw_end_cap.stl
hardware/stl/pw_hopper.stl
hardware/stl/pw_housing.stl
hardware/stl/pw_wheel.stl

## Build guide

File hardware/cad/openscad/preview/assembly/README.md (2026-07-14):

# preview/assembly — «як збирається AiPetFeeder» (форма 1a)

Рендери генеруються **без `--render`** (preview-режим — інакше злітають кольори).
Джерело: `bulk_hopper_module.scad` + `gallery_views.scad`.

## Що де

| Файли | Що показують | part / view |
|---|---|---|
| `step_0..9.png` | Покрокова збірка, кумулятивно (порядок §3 HANDOFF) | `part="step"` `step=N` |
| `x_base_*`, `x_tower_*`, `x_funnel_*` | Розібрані види (iso + фронт) | `part="x_base"` … |
| `full_cut_iso.png` | Вертикальний розріз вежі (housing↔cap↔cone, колесо під cap) | `part="full_cut"` |
| `food_path.png` | Шлях корму до лотка + 45° рампа задньої стінки | `view="food"` `cut="yhalf"` |
| `base_cut.png` | База в розрізі: дно, cell, пʼєдестал, лоток, відсік | `part="base_cut"` |
| `nest_check.png` | Верхня стінка housing у пазу кришки | `part="nest_check"` |
| `bayonet_iso.png` | J2 байонет, зум на locked-таб | `part="bay_zoom"` |
| `product_25/115/205/295.png` | Готовий виріб, turntable | `part="full"` |

## Перегенерувати

```sh
cd hardware/cad/openscad
# крок
xvfb-run -a openscad -o preview/assembly/step_5.png --imgsize=800,1000 --viewall --autocenter \
  --camera=0,0,0,60,0,30,0 -D 'part="step"' -D 'step=5' bulk_hopper_module.scad
# шлях корму (yhalf лишає y<0 → дивись з +Y: rz≈195)
xvfb-run -a openscad -o preview/assembly/food_path.png --imgsize=1000,820 --viewall --autocenter \
  --camera=0,0,0,76,0,195,0 -D 'view="food"' -D 'cut="yhalf"' gallery_views.scad
```

> **НЕ запускай пакет у фоні паралельно** — кілька `xvfb-run` б'ються за X-дисплей і
> тихо падають (файли не створюються). Ганяй синхронно.
>
> **`bay_zoom`** найкраще дивитись інтерактивно в OpenSCAD GUI (крутити): таби 8 мм на
> Ø160 з фіксованого ракурсу дрібні. Функціональність байонета доведена ЧИСЛОМ у `_chk.scad`
> (вхід 0 tris, дах над locked-табом 24 tris), не картинкою.

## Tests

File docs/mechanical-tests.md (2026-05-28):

# Mechanical tests — feeding mechanism

Goal of Stage 1: find a feeding mechanism that moves **real cat food**
reliably, without jamming, with a roughly repeatable portion. Two
candidates are being benchmarked head-to-head:

1. **Paddle wheel** — primary candidate; expected to win. Pockets fill
   and empty by gravity; no kibble shear.
   Model: `hardware/cad/openscad/paddle_wheel_module.scad`.
2. **Auger** — benchmark only; expected to jam (per the user's prior
   experience with screw-and-kibble feeders).
   Model: `hardware/cad/openscad/feeder_test_module.scad`.

Everything else (firmware, weight loop, enclosure) waits on this. See
`docs/project-notes.md` and `hardware/bom.md`.

## How to run one test

1. Print one **variant** (auger+barrel or wheel+housing — record which).
2. Mount on NEMA17, fit the matching hopper, fill with the **actual
   food the cat eats**.
3. Drive a fixed amount of motion (start: 5 motor revolutions for the
   auger; for the wheel, N pockets where N = wheel's `n_paddles`, i.e.
   one full rotation).
4. Weigh what came out (kitchen scale, grams).
5. Repeat the **same** run 5× without changing anything in between.
6. Record below. One table row per printed variant.

Keep failed variants' rows — knowing what *didn't* work is the point.

## Test setup (fill once, update when it changes)

- Food (brand / kibble size & shape):
- Scale (model / resolution):
- Motor / driver / microstepping:
- Revolutions per run:
- Anti-jam reverse used (steps back per run): none / ___

## Results — paddle wheel

| Date | Variant id | wheel_d | wheel_width | n_paddles | housing_clear | Runs (g, each) | Mean g | Spread (max−min) | Jam? | Notes |
|---|---|---|---|---|---|---|---|---|---|---|
| | | | | | | | | | | |

## Results — auger (benchmark)

| Date | Variant id | auger_od | pitch | flight_thick | barrel_clear | Runs (g, each) | Mean g | Spread (max−min) | Jam? | Notes |
|---|---|---|---|---|---|---|---|---|---|---|
| | | | | | | | | | | |

`Variant id` = short tag you write on the printed part (e.g. `W1`, `A1`).

## Decisions log

Record conclusions as they emerge — these drive Stage 2 / BOM updates:

- Best variant so far:
- Open-loop portion repeatable enough, or HX711 weight loop mandatory?
- Vibration motor needed (did food bridge/jam)?
- NEMA17 17HS4401 overkill → downsize?
- Anti-jam reverse: how many steps back per portion works?

## Status

- [ ] At least one variant moves food without jamming
- [ ] Portion spread acceptable across 5 repeats (define threshold above)
- [ ] Decided: open-loop vs weight-loop dosing
- [ ] Decided: vibration motor in/out
- [ ] Stage 1 passed → unblock Stage 2

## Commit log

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2026-05-19 Add through-axle, D-flat coupling, inlet funnel and feed hopper
    - auger: through D-bore so a Ø5 mm axle passes all the way through
    - axle: new part — round stubs both ends, D-flat over the auger
    engagement length (this flat is the torque key, not a slip fit)
    - barrel: conical inlet funnel narrowing to the bore + a rectangular
    socket collar
    - hopper: new part — feed cone, round top to a rectangular spout that
    plugs into the barrel socket collar (removable for cleaning)
    - previews regenerated + axle/hopper added; BOM updated (axle + coupler)
    Verified in OpenSCAD 2021.01: all parts Simple:yes (manifold);
    assembly fit checked visually.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
    [feeder_test_module.scad]
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2026-05-20 Add paddle-wheel mechanism (primary Stage 1 candidate)
    Per user's prior experience: auger + cat kibble jams even with
    forward/back step compensation. Pivot the primary mechanism to a
    paddle wheel (vane wheel; same architecture as GyverFeed2). Auger
    is now a benchmark only.
    - paddle_wheel_module.scad: parametric wheel (N paddles, through D-bore
    for the same Ø5 mm axle the auger uses), closed cylindrical housing
    with rectangular top inlet boss + bottom outlet chute (rectangular
    through-cuts, no arc-extrude wedge artifacts), feed hopper that
    plugs into the boss socket. All four parts manifold (Simple:yes),
    assembly fit verified visually.
    - STL + 3MF exports (pw_*) + preview renders.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
    [paddle_wheel_module.scad, pw_axle.3mf, pw_axle.stl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]
2026-05-20 Split paddle-wheel housing: open top + removable end_cap
    The previous housing was a closed cylinder with only the axle bores
    and the inlet/outlet openings — you couldn't physically insert the
    60x30 mm wheel into a 66x30 mm cavity. Refactor:
    - housing: now a cup (closed bottom, OPEN top). Rim has a recess of
    depth register_d=1.5 mm, widened by step_w=1 mm radially.
    - end_cap: new part. Disc + register lip on the underside that drops
    into the rim recess (slip fit, 0.2 mm clearance). Carries the
    upper axle bore. No screws for Stage 1 — gravity + friction +
    optional rubber band.
    - boss_flare: 4 -> 2 and outlet_w: 28 -> 24 so the boss and chute
    fit within housing_h and don't confli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
    [paddle_wheel_module.scad, pw_axle.3mf, pw_end_cap.3mf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]
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2026-05-21 Paddle wheel: axial clearance + non-coaxial inlet/outlet
    First-print findings from the user:
    - pw_wheel didn't fit: the cavity was exactly wheel_width with zero
    axial slack, plus housing_clear was too tight for FDM tolerances.
    - pw_end_cap couldn't close: the wheel top occupied the rim recess
    where the cap lip needs to sit.
    Fixes:
    - New wheel_axial_clear = 0.5 mm; housing_h grows by that + register_d
    so the wheel top sits below the cap recess.
    - housing_clear bumped 0.6 -> 0.8 (radial play wheel <-> cavity).
    - fit_clear bumped 0.20 -> 0.30 (axle bores + cap lip seat).
    Geometry change (also user-requested):
    - inlet/outlet angular positions are now parametric (inlet_angle_deg,
    outlet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
    [paddle_wheel_module.scad, pw_axle.3mf, pw_end_cap.3mf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]
2026-05-21 Paddle wheel: rebuild as rotary-disc dispenser (axial inlet/outlet)
    Per user feedback after first physical test: the radial side-port
    architecture was wrong. The correct layout has the inlet and outlet
    PARALLEL to the wheel axis (0° to the axle), not radial (90°).
    - Housing now lies on its flat circular floor. Outlet is a
    rectangular hole through that floor (not a side chute).
    - End_cap carries the inlet hole at a radial offset, with the
    hopper boss-socket on top.
    - Wheel: full-height hub for axle support; paddles fill only the
    BOTTOM HALF of the cavity (paddle_fraction = 0.5) so kibble drops
    past them into a pocket on the floor, then gets swept around the
    floor to the outlet po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
    [paddle_wheel_module.scad, pw_axle.3mf, pw_axle.stl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]
2026-05-24 Paddle wheel: scale up to Ø80 mm to fix kibble-hole jam
    Physical test 2026-05-24 with real cat kibble showed the previous
    16×12 mm inlet/outlet rectangles were ~equal to one kibble piece —
    guaranteed jam. Photos confirmed barely-enough-for-one-piece geometry.
    Changes (option C from user choice):
    - wheel_d: 60 → 80 mm
    - hub_d: 16 → 20 mm (kept proportional)
    - hole_radial_in: 10 → 18 mm
    - hole_radial_out: 26 → 38 mm
    - hole_w: 12 → 22 mm (chord at r=18, n=4 = 23.7 mm → 0.85 mm
    paddle-clearance margin each side)
    Result: inlet/outlet rectangles now 20×22 mm — two kibble pieces fit
    comfortably side by side. Housing OD grows 67.6 → 87.6 mm. Pocket
    volume ~33 mL ≈ 13 g por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
    [paddle_wheel_module.scad, pw_axle.3mf, pw_end_cap.3mf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]
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2026-05-25 Add bulk hopper module: funnel + storage ring + lid + anti-bridge cone
    Product-direction pivot (see ADR 2026-05-25-fully-printed-product-
    direction): fully-printed feeder with 2 kg bulk capacity. First
    iteration ships funnel + 1 ring + lid = ~4.2 L = ~1.7 kg.
    bulk_hopper_module.scad parts:
    - funnel: Ø160 × 153 mm. Mass-flow 65° walls (kibble internal-friction
    angle ~33° → mass-flow guaranteed). Integrated anti-bridge cone
    (Ø40 base, 35 mm tall, suspended on 4 radial ribs) positioned at
    55% of funnel height. Rectangular spout below matches the paddle-
    wheel cap socket. Top stacking lip.
    - ring: Ø160 × 170 mm modular storage section, stacks via slip-fit lip
    (3 mm wall, 0.3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
    [bh_funnel.3mf, bh_funnel.stl, bh_lid.3mf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]
2026-05-25 Add lower body chassis with internal chute + side outlet
    Per user product-direction feedback: rotary outlet routed laterally
    to a bowl niche on the front face of an integrated chassis. C-shape
    architecture (Petlibro-style integrated bowl).
    chassis_module.scad:
    - 220×200×160 mm rectangular body
    - Top: cylindrical recess (Ø88.6) that seats the rotary housing
    - Bowl niche: 130×160×80 mm front-bottom cavity (off-the-shelf bowl
    up to Ø140 mm, sits inside with 10 mm clearance, protrudes 30-40 mm
    out the front for cat ergonomics)
    - Internal slanted CHUTE: catches kibble from the housing floor
    outlet (at chassis +X side) and routes it down-and-forward through
    the chassis body to a fro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
    [chassis.3mf, chassis.stl, chassis_module.scad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]
2026-05-25 Bigger redesign: collar-mount hopper, no spout walls, rounded hole corners
    Per ADR 2026-05-25-collar-mount-hopper-redesign in the vault. Physical
    test 2026-05-25 confirmed the 20×22 hole (after the Ø60→Ø80 enlargement)
    still jams — diagnosis showed the jam is at the SHELF + SPOUT WALL
    constriction, not the hole size. Spout-in-socket architecture replaced
    with hopper-sits-ON-cap (collar mount). Eliminates wall narrowing of
    the kibble flow pipe.
    paddle_wheel_module.scad changes:
    - n_paddles 4 → 3 (sectors 120°, room for wider hole)
    - wheel_thickness 26 → 18 mm (portion still ~11 g)
    - hole_radial_out 38 → 40 mm (hole_len 22)
    - hole_w 22 → 28 mm
    - NEW: hole_corner_r = 2 mm (roun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
    [bh_funnel.3mf, bh_funnel.stl, bh_lid.3mf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]
2026-05-26 Anti-bridge cone: tip-up + ribs clipped to funnel outer
    Two fixes the user caught in the previous render of the bulk hopper:
    1. Ribs were extending ~33 mm beyond the funnel exterior — sticking out
    into open air on each side, visible as tabs. Cause: rib_outer_r=75
    was sized for the old frustum funnel; after the rect→round hull
    rewrite the funnel wall at the cone z-position is only ~42 mm from
    axis. Fixed by clipping the cone+ribs union with intersection()
    against the funnel outer hull — ribs now end exactly at the outer
    surface, not beyond. Funnel exterior is smooth again.
    2. Anti-bridge cone was tip-DOWN (wide flat horizontal at top). User
    correctly identified th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
    [bh_funnel.3mf, bh_funnel.stl, bulk_hopper_module.scad]
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2026-05-28 Hopper/funnel: add straight bottom plug for cap collar fit
    User caught a geometric conflict: hopper/funnel cone started tapering
    outward at z=0 (the cap top), but the cap collar has straight vertical
    walls. After ~2-3 mm above cap, the funnel outer was wider than the
    collar inner — the parts couldn't actually plug together.
    Fix in both `pw_hopper` (test hopper) and `bh_funnel` (bulk hopper):
    - z=0 to z=10 (= cap_collar_h): straight rect tube, outer 26×32 rounded
    → slides into the cap collar with 0.5 mm clearance per side
    - z=10 to z=hopper_h: tapered hull cone (round top), as before
    - Inner cavity matches: straight 22×28 at the bottom plug, tapered above
    bulk_hopper_module.scad: n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
    [bh_funnel.3mf, bh_funnel.stl, bulk_hopper_module.scad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]
2026-05-28 Upscale wheel Ø80→120, hole 22×28→35×35 (anti-bridge)
    Static kibble bridging persisted across every prior redesign of the
    rotary disc (rounded corners, collar-mount, spider, straight plug):
    ratio kibble:hole stayed at ~2:1, below the ~4:1 mass-flow threshold.
    Bumping the wheel to Ø120 brings the hole to 35×35 and the ratio to
    ~3:1 — much less prone to static bridging. Pocket volume grows from
    ~28 mL to ~35 mL; portion goes from ~11 g to ~14 g (still single-meal).
    Changes:
    - paddle_wheel_module: wheel_d 80→120, hub_d 20→30, wheel_thickness
    18→10 (pocket area grew), hole 22×28→35×35, hole_radial_in/out
    18/40→22/57. Housing OD 87.6→127.6 mm, housing_h 23.5→15.5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
    [bh_funnel.3mf, bh_funnel.stl, bh_lid.3mf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]
2026-05-28 Round paddle tips (semicircle r=1.2 mm in plan view)
    The old 90° paddle tip + housing wall corner formed a wedge that
    caught kibble between them — user reported jams across every
    wheel/housing version, independent of wheel size.
    Now: paddle body stops paddle_thick/2 (= 1.2 mm) short of wheel_r,
    and a cylinder Ø=paddle_thick caps the tip. Net result: paddle still
    sweeps to wheel_r (outer envelope unchanged), but the tip is a smooth
    semicircle in plan view — kibble at the tip-wall interface gets
    pushed tangentially instead of wedged.
    Z-direction edges unchanged (sharp top/bottom on paddle). If vertical
    edge wedging shows up next, we round those too.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
    [paddle_wheel_module.scad, pw_wheel.3mf, pw_wheel.stl]
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2026-05-29 Funnel: uniform 2 mm cone wall (was gradient 2 → ~8 mm)
    User noticed the funnel cone's wall was gradually thickening toward
    the top. Two stacked bugs:
    1. funnel_cavity hull top was at z=funnel_h+joint_lip_h+2 (=152) with
    r=bulk_r_in (=77), while funnel_outer hull top was at z=funnel_h
    (=140) with r=bulk_d/2 (=80). The cavity didn't reach its full
    radius by the time the outer ended → wall at z=140 was ~8 mm
    instead of the intended 2 mm.
    2. Same cavity hull also carved through the stacking_lip's wall,
    leaving the lip with only ~0.5 mm material at its top (was
    supposed to be 3 mm).
    Fix: split funnel_cavity into two:
    • Cone cavity hull rect → circle r=(bulk_d/2 - h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
    [bh_funnel.3mf, bh_funnel.stl, bh_spider.3mf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]
2026-05-29 Housing: taller walls — add 15 mm kibble buffer above wheel
    User reported pw_housing was too short. Before: 15.5 mm total height
    (wheel 10 + clearances 5.5), so only ~2 mm of dead space between the
    wheel TOP and the cap INLET. Kibble pieces (~12 mm) physically had
    no room to settle before hitting the wheel — likely caused some of
    the bridging seen in earlier tests.
    Added housing_buffer_h = 15 mm parameter. New total housing height
    30.5 mm. Multiple kibble pieces can now pre-stack in the buffer
    zone and feed into pockets as the wheel rotates under the inlet.
    Side effects:
    - Axle grows from 48.5 → 58.5 mm (housing_h is part of axle total)
    - chassis_module's housing_height comment + ass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
    [chassis.3mf, chassis_module.scad, paddle_wheel_module.scad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]
2026-05-29 Funnel: more open cone (140→110 mm) + clarify print orientation
    User asked for a less aggressive cone slope: kibble should slide,
    not "stand" on walls. Bumped funnel_h from 140 to 110 mm. Wall
    angle from vertical goes from 25° (very steep) to 31° — well below
    the kibble mass-flow critical angle of ~33°, but visibly more open.
    Cone capacity drops ≈ 27 g (1.17 → 0.90 L per cone). Total feeder
    capacity with one ring goes 1.73 → 1.62 kg.
    Also clarified print orientation in BOM. User's screenshot showed
    the funnel oriented round-end-down with the lip-cone outer step
    exposed as a 3.3 mm overhang. The correct orientation is RIGHT-SIDE
    UP (rect plug on bed = OpenSCAD's default export)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
    [bh_funnel.3mf, bh_funnel.stl, bh_spider.3mf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]
2026-05-29 Cap printable without supports + 4-pin rotational index
    Two problems user spotted in OrcaSlicer:
    1. pw_end_cap.stl had an 8.3 mm radial unsupported overhang at the
    disc/lip step (register lip ~Ø111 below disc Ø127.6).
    2. Free rotation of cap on housing — no rotational positioning.
    Both fixed with one redesign of the housing-cap interface:
    - REMOVE the register lip from the cap underside.
    - REMOVE the matching rim recess from the housing top.
    - ADD 4 small pins (Ø2 × 3 mm tall) on the housing top rim at
    45°/135°/225°/315° (relative to outlet 0°).
    - ADD 4 through-holes (Ø2.4) at the same angular positions in the
    cap disc.
    Cap now prints disc-bottom-on-bed (flat) with NO ov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
    [paddle_wheel_module.scad, pw_axle.3mf, pw_axle.stl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]
2026-05-29 Fix lip's first-layer floating region (slicer warning)
    User screenshot from OrcaSlicer showed the lip's first layer printing
    in mid-air with the "floating regions" warning. Root cause: my earlier
    "uniform 2 mm cone wall" fix had the cone wall at z=funnel_h spanning
    r=78 to r=80, but the lip wall above it spanned r=73.7 to r=76.7 —
    the two annular rings don't overlap radially, so the lip prints over
    the cone's cavity (= empty space).
    Fix: add a 5 mm cavity_taper_h chamfer at the top of the cone. Cone
    cavity narrows from r=78 to r=lip_ir (=73.7) over 5 mm. Cone outer
    stays at Ø bulk_d throughout. Result at z=funnel_h: solid annular
    wall from r=73.7 to r=80 (6.3 mm thick) — supports the l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
    [bh_funnel.3mf, bh_funnel.stl, bh_spider.3mf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]
2026-05-29 Robust pin redesign — Ø3 + thickened rim + chamfered base
    User feedback: previous Ø2 × 3 mm pins on a thin 3 mm rim looked
    fragile in OrcaSlicer ("не надійно"). They were structurally
    sufficient (~157 N shear per pin) but easy to snap in handling.
    Considered moving the lock to the cap side (downward features) but
    all such designs hit the same bridging issue: the cap MUST print
    disc-on-bed (because the collar sticks up without supports), and
    any downward protrusion is too small to support the much larger
    disc above it. So the lock topology stays the same (pins on housing,
    holes in cap) but the pins are now much beefier:
    - Housing top 6 mm of the wall is thickened INWARD by 2 m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
    [paddle_wheel_module.scad, pw_axle.3mf, pw_end_cap.3mf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]
2026-05-29 Anti-rotation lock: pins → outward tabs + slotted ears
    User's idea: make the lock features horizontal (in the cap's bottom
    plane) instead of vertical pins. Both parts now print support-free and
    the lock is far more robust than Ø3 pins.
    - Cap: 4 outward tabs at the disc edge (8×3×3 mm, in-plane first-layer
    extensions). Old Ø3.4 pin holes removed.
    - Housing: 4 outboard slotted ears (2 prongs each) that the tabs drop
    into. Chamfered self-supporting underside starting above the chassis
    recess → no chassis relief needed (chassis untouched).
    - Reverted the inward rim thickening (its only purpose was pin material);
    wheel buffer is full-width again.
    Verified: openscad --render clea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
    [paddle_wheel_module.scad]
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2026-06-03 Downscale mechanism to Ø80 + vibromotor mount, drop the spider
    Switch from passive (big wheel) to ACTIVE anti-bridge (vibromotor) + the
    planned HX711 closed loop, so the whole mechanism shrinks back to the Ø80
    baseline while keeping all iter2 improvements (tab/ear lock, rounded
    paddles, lip-support fix, print orientations). Funnel/storage stays Ø160
    (variant B — only the mechanism shrinks).
    paddle_wheel: wheel_d 120->80, thickness 10->18, hub 30->20, hole
    35x35->22x28. Housing OD 87.6, housing_h 37. Lock + buffer auto-scale.
    bulk_hopper: hole 22x28 (match). Removed the anti-bridge SPIDER (it was
    the bridge source) + added an external VIBROMOTOR PAD near the throat
    (placeholder fa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
    [bh_funnel.stl, bh_spider.stl, bulk_hopper_module.scad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]
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2026-06-04 Lock v4: flush rim merlons + cap notches (no protruding ears)
    User: the v3 outward ears/tabs stuck out past the wall. v4 keeps the
    anti-rotation entirely WITHIN the wall thickness — nothing protrudes:
    - housing: 4 rim MERLONS (wall raised lock_rise at 4 spots, confined to
    the hr_in..hr_out band)
    - cap: 4 full-thickness edge NOTCHES; merlons poke through → 4 index
    positions
    Both still print support-free (raised wall = vertical; notch = a gap,
    nothing bridges). STLs regenerated, single-component.
    [paddle_wheel_module.scad, pw_end_cap.stl, pw_housing.stl]
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2026-06-05 Funnel: revert cone to steepest (better overhangs) + lighter vibro pad
    User print test: more-open cone (36deg) printed worse on overhangs, and
    the vibro pad underside drooped.
    - cone_top_z 98->110: cone runs full height (~31-33deg from vertical),
    least overhang at this height. Bigger 26x34 throat kept (real anti-bridge
    lever); to go steeper would need a taller funnel.
    - vibro pad: smaller (14 wide, face r33), steeper underside ramp
    (vibro_ramp=1.4, ~35deg vs 45deg), + central lightening hole = less
    material + holes. Still a placeholder (motor spec pending).
    bh_funnel STL regenerated, single-component.
    [bh_funnel.stl, bulk_hopper_module.scad]
2026-06-05 Vibro mount: flat shelf + integrated breakaway support (user choice B)
    Replace the overhang-prone wedge pad with a flat shelf (motor mounts on
    the top face) near the throat. A thin 1.2mm support wall runs bed->shelf
    outer edge so the underside prints as a ~9mm bridge; user snaps the wall
    off after printing. Holes are vertical through the shelf (2 pilot + 1
    central clearance) — placeholder pattern pending the motor spec.
    bh_funnel single-component.
    [bh_funnel.stl, bulk_hopper_module.scad]
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2026-06-05 Lock v5: robust merlons (longer + inward-thickened + anchored)
    A v4 merlon snapped off easily (thin 3x8mm tab, 5mm tall). v5 makes them
    hard to break:
    - longer tangentially (lock_w 8->14), lower (rise 5->4) = more base, less
    leverage
    - thickened inward (lock_thick=3 -> 6mm radial) into the empty buffer
    - chamfered anchor ramps the thickening into the wall below the rim (no
    thin neck; self-supporting)
    - merlons unioned after the cavity cut so the inward part survives
    - cap notches resized to match the bigger merlon footprint + clearance
    Outer wall still flush (no radial protrusion). housing + cap single
    component, no manifold warnings.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
    [paddle_wheel_module.scad, pw_end_cap.stl, pw_housing.stl]
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2026-06-06 Teardrop housing + cap (round bottom -> teardrop top, bigger inlet)
    User test: the funnel with the biggest opening flows best. To grow the
    cap inlet without growing the round wheel, the housing stays ROUND at the
    bottom (wheel) and flares to a TEARDROP at the top, tip pointing back
    toward the inlet; the cap is the matching teardrop with a big teardrop
    inlet (+22mm back, user choice). The teardrop shape orients the cap, so
    the (snapping) merlons are removed.
    - new teardrop_2d / inlet_2d helpers; td_* + inlet_* params
    - housing: round cup flaring to teardrop top; round floor outlet unchanged
    - cap: teardrop disc + teardrop inlet + teardrop collar; no merlons/notches
    All single-component, no wa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
    [paddle_wheel_module.scad, pw_end_cap.stl, pw_housing.stl]
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2026-06-06 Housing outlet: taper the floor hole so the wheel doesn't catch
    User: the floor outlet has straight 90deg walls and the paddle wheel
    sometimes catches on the sharp top edge. Made the outlet TAPERED (hull of
    a nominal rounded-rect at the exit and a wider one at the floor surface,
    out_cham=2): the wheel side is now a sloped lead-in, the exit stays
    nominal. housing single-component, no warnings.
    [paddle_wheel_module.scad, pw_housing.stl]
2026-06-06 Outlet: slope the tangential edges + pull it off the rim (no wheel catch)
    User circled the two tangential edges of the floor outlet — the ones the
    paddle crosses — they catch. Two fixes:
    - pulled hole_radial_out 40->35 so the paddle TIP sweeps solid floor near
    the rim and never crosses a hole edge there (hole_mid_r 23.5->21;
    chassis chute outlet_x updated)
    - the two tangential edges are now SLOPED (out_cham=3, wider at the wheel
    side); radial edges stay vertical. Stays clear of the wall/OD.
    housing + chassis single-component, no warnings.
    [bulk_hopper_module.scad, chassis.stl, chassis_module.scad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]
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2026-06-07 funnel: add drop-in anti-pressure spider (stress cone)
    Full hopper put too much head pressure on the wheel (couldn't turn). A
    static stress cone seated in the throat bears the kibble column on a
    central cone (apex up) and shunts it into the funnel wall via 3 legs, so
    only a thin low-pressure layer reaches the wheel. 3 wide gaps keep flow
    (no arch). Cork-seats on the diverging cone wall (legs clipped to the
    cavity). part="spider" prints it; part="spider_fit"/"spider_cover"
    are clearance/coverage checks.
    [bulk_hopper_module.scad]
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2026-06-08 fix funnel through-holes + add glueless snap detent for legs
    - HOLES: spider_slots cut extended 30mm above the boss → it sliced the bare
    2mm wall = through-holes. Bound the slot z to [rest, rest+key_h] (inside the
    boss), so a 4mm back wall always remains. Verified: clean ring above the
    boss, backed slots at the slot level.
    - DETENT: a bump on each leg face clicks into a dimple in each body socket
    wall → legs snap in and hold with no glue (sp_det_*). funnel_xsec now takes
    -D xsec_z=NN.
    [bulk_hopper_module.scad]
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2026-06-08 spider rework: inward rest-ledges + 3mm body floor (no outward bosses)
    User feedback: (1) pear bottom too thin to hold legs → sp_body_floor=3mm of
    material below the sockets; (2) dislike outward bosses → removed them, the
    funnel keying is now small INWARD ledges (підставки, ~1.5mm, ramped) the legs
    LAY on (load into the wall, no spreading) + small side keys for anti-rotation;
    (3) all features inside + gentle + ramped → kibble flows past, prints without
    supports. Assembled spider drops in; legs clipped to the wall clear the wider
    cone above and land on the ledges. Removed the outward boss/slot machinery.
    [bulk_hopper_module.scad]
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2026-06-16 spider: real capture pockets in the funnel wall (legs were just balancing)
    Printed test showed the legs only LAID on 1.5mm ledges with 1.2mm side keys —
    nothing caught them, so the spider rotated and dropped into the outlet.
    Replace spider_ledges with spider_pockets: each leg tip drops INTO a slot =
    ramped 7mm floor (load + no fall) + two 11mm side walls (anti-rotation) + the
    funnel wall as radial backstop. Floor underside ramped (8>7 → ≤45°) so it still
    prints support-free. Horizontal xsec confirms 3 clean channels; CGAL clean.
    Only the FUNNEL changes — spider body/legs unchanged (no reprint needed).
    Regenerated bh_funnel STL/3MF.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
    [bh_funnel.3mf, bh_funnel.stl, bulk_hopper_module.scad]
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
